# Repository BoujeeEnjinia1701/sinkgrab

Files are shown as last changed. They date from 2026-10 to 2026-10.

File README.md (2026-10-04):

# SinkGrab

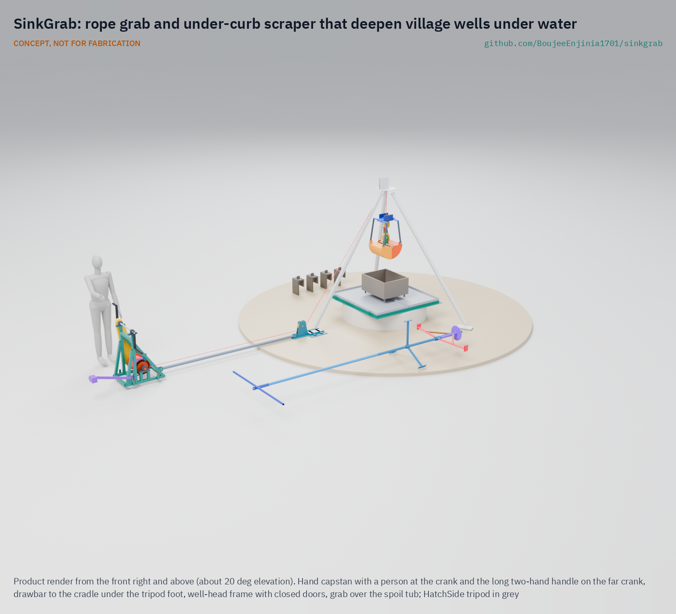
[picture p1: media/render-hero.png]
SinkGrab: rope grab and under-curb scraper that deepen village wells under water


     

**Area:** Food and water security · **TRL:** 3 of 9 (proof of concept on paper; constructable design) · **Value-engineering target:** USD 4,000; estimated parts cost USD 2,566 · **Difficulty:** 3 of 5

Deepens village wells under water with a rope grab and under-curb scraper, without divers or pumps.

> CONCEPT, NOT FOR FABRICATION. SinkGrab is a TRL 3 design on paper: it has not been built or tested.

## Concept rationale

A hand-dug well only gives water all year if its intake sits well below the lowest seasonal water level. Guidance for caisson wells is to keep excavating and sinking rings typically 2 to 3 m below the water table ([Abbott, Hand Dug Wells manual](https://sswm.info/sites/default/files/reference_attachments/ABBOT%204000%20Hand%20Dug%20Well%20Manual.pdf)). Without de-watering the practical limit is about 1 m ([Akvopedia](https://akvopedia.org/wiki/Traditional_hand-dug_wells)). The usual answers are a motor pump to bail the well, or a person working under water. SinkGrab removes both: the digging and the undercutting are done by tools on ropes, worked from the surface.

SinkGrab is two tools and a routine. A rope-closed grab bites soil from the bottom of the flooded well inside the caisson rings and lifts it out. An under-curb scraper reaches under the cutting edge of the bottom ring so the lining sinks evenly as the soil is removed. Both hang from the HatchSide tripod and are worked with a hand capstan, so the crew stays at the top. Everything is built from steel section, rope and hand tools, and is published under open licences so village fabricators can copy and repair it.

## Burning platform

About 296 million people still drink from unprotected wells or springs ([Our World in Data, from WHO/UNICEF JMP 2024](https://ourworldindata.org/what-no-safe-water-means)). Many more rely on protected hand-dug wells that fail in the dry season: 'Hand-dug wells have a tendency to have very little water or even dry up in the dry season', largely because the intake is not deep enough below the seasonal water table, which can move several metres between seasons ([Akvopedia](https://akvopedia.org/wiki/Traditional_hand-dug_wells)). In Ethiopia's 2015/16 drought, hand-dug wells dried up while monitored boreholes kept the same flow all year, and people without boreholes queued for up to 10 hours for water ([BGS](https://www.bgs.ac.uk/news/study-shows-boreholes-are-key-to-drought-resilience-in-ethiopia/)).

Going deeper under water is dangerous. Oxfam's guidance says a diesel or petrol pump or its engine must never be lowered into a well, because carbon monoxide collects there ([Oxfam WASH](https://www.oxfamwash.org/repairing-cleaning-and-disinfecting-hand-dug-wells/)). In August 2023 three men died in Mutare, Zimbabwe, while draining a well about 19 m deep with a petrol pump ([ZimLive, 2023](https://www.zimlive.com/3-killed-in-carbon-monoxide-poisoning-after-turning-on-generator-in-a-well/)). In August 2026 four men died of suspected toxic gas while repairing a motor inside a well in Gaya Ji, Bihar ([The Tribune, 2026](https://www.tribuneindia.com/news/india/4-die-of-asphyxiation-after-inhaling-toxic-gas-inside-well-in-bihars-gaya-ji/)). Every hour a person spends at the bottom of a well is exposure; tools that dig from the surface cut that exposure.

## Where it could be used

### By industry

| Industry | Use |
| --- | --- |
| Rural water supply and WASH programmes | Deepening existing hand-dug wells so they last through the dry season |
| Well-digging contractors and village fabricators | A safer, pump-free way to finish the wet part of a new caisson well |
| Smallholder irrigation | Deepening dug wells used for garden and livestock water |
| Drought and humanitarian response | Rehabilitating dry community wells quickly with a kit that travels on a pickup |
| Small civil works | Sinking small precast caissons for pump sumps and soakaways |
| Engineering education | A documented case study in caisson sinking, rope mechanics and field safety |

### By country or region

| Country or region | Why it matters there |
| --- | --- |
| India (Kerala) | About 65% of rural and 59% of urban households depend on wells, and 48% of 45 lakh wells surveyed in 2003 dried up in summer ([SOPPECOM, citing Census 2011 and the Kerala Water Authority](https://www.soppecom.org/pdf/Groundwater-Resource-and-Governance-in-Kerala.pdf)). |
| India (Thiruvananthapuram) | Well diggers report that in summer they must dig an extra 10 to 15 feet (3 to 4.5 m) down, and one crew dug more than 70 wells in three months ([Deccan Chronicle, 2017](https://www.deccanchronicle.com/nation/in-other-news/040517/thiruvananthapuram-well-diggers-strike-gold-in-summer.html)). |
| Ethiopia | In the 2015/16 drought hand-dug wells dried up and many became grossly contaminated, while boreholes held their flow ([BGS](https://www.bgs.ac.uk/news/study-shows-boreholes-are-key-to-drought-resilience-in-ethiopia/)). |
| Zimbabwe | Three men died of carbon monoxide in 2023 while draining a 19 m well with a petrol pump, the risk SinkGrab is designed to remove ([ZimLive, 2023](https://www.zimlive.com/3-killed-in-carbon-monoxide-poisoning-after-turning-on-generator-in-a-well/)). |
| Global | About 296 million people use unprotected wells or springs ([Our World in Data, 2024 JMP data](https://ourworldindata.org/what-no-safe-water-means)); upgrading and deepening dug wells is one of the cheapest paths to year-round water for them. |

## What sparked the idea

In August 2023 three men in Mutare, Zimbabwe, were draining a well about 19 m deep so they could work at the bottom. The petrol pump they used filled the shaft with exhaust and all three died ([ZimLive, 2023](https://www.zimlive.com/3-killed-in-carbon-monoxide-poisoning-after-turning-on-generator-in-a-well/)). Oxfam's field guidance forbids exactly this ([Oxfam WASH](https://www.oxfamwash.org/repairing-cleaning-and-disinfecting-hand-dug-wells/)), yet the job still has to be done, because a well that is not deep enough goes dry. SinkGrab starts from that gap: if the water cannot safely be taken out, the soil has to be.

## Problem

Hand-dug wells go dry in the dry season because crews cannot dig far enough below the water table without pumps, and pumps and divers in wells kill people. Well diggers need a way to keep digging under water and sink the lining from the surface.

Full problem statement: [docs/01-problem.md](docs/01-problem.md)

## Concept

A rope grab and under-curb scraper worked from the HatchSide tripod and a hand capstan; well diggers lower them into a flooded hand-dug well to dig soil out under water and undercut the curb ring so the lining sinks, without divers or pumps. One 8 mm line does everything: the grab goes down closed, its head's weight opens it on the bottom, and two people at the cranks, three during the hoist, close it through a 3:1 tackle on a bite of about 21 L and lift it. A shear link and a crank shear pin keep the line inside the tripod's 150 kg rating. The scraper's arms open under the cutting edge when the pole's weight rests on its foot, and two people turn it with a T-bar through the closed well-head doors.

Full design precis: [docs/02-concept.md](docs/02-concept.md) · Requirements: [docs/03-requirements.md](docs/03-requirements.md) · Calculations: [docs/04-calcs/01-sizing.md](docs/04-calcs/01-sizing.md) · Prototype build plan: [docs/05-build-plan.md](docs/05-build-plan.md) · Design decisions: [docs/06-design-decisions.md](docs/06-design-decisions.md)

## Key components

- Hand capstan: winding drum, 4:1 chain with a shear pin hub, pawl, weighted band brake, removable cranks
- Foot cradle with lead sheave under the HatchSide leg A foot, and a drawbar back to the capstan
- Two-shell clamshell grab on one closing line, with a shear link at its tackle
- Under-curb scraper head on 2 m pole sections, turned with a T-bar
- Well-head frame with folding doors, pole hole and tilt datum; spoil tubs
- Ballast saddles (8) and a dip tape and plumb line for tilt
- Four-gas detector and barrier kit

## Building the prototype

The capstan, cradle, drawbar, grab, scraper, well-head frame and saddles are welded from stock steel tube, plate and bar, with the shell skins rolled and a few plates profile-cut; the bearings, chain drive, sheaves, ropes and rigging are bought. The build plan takes a capable maker through every component in build order with a making sketch, joint close-ups and a picture for each of its 20 assembly steps, and lists the safety stops before anything is lifted over a well. It is a plan, not yet built.

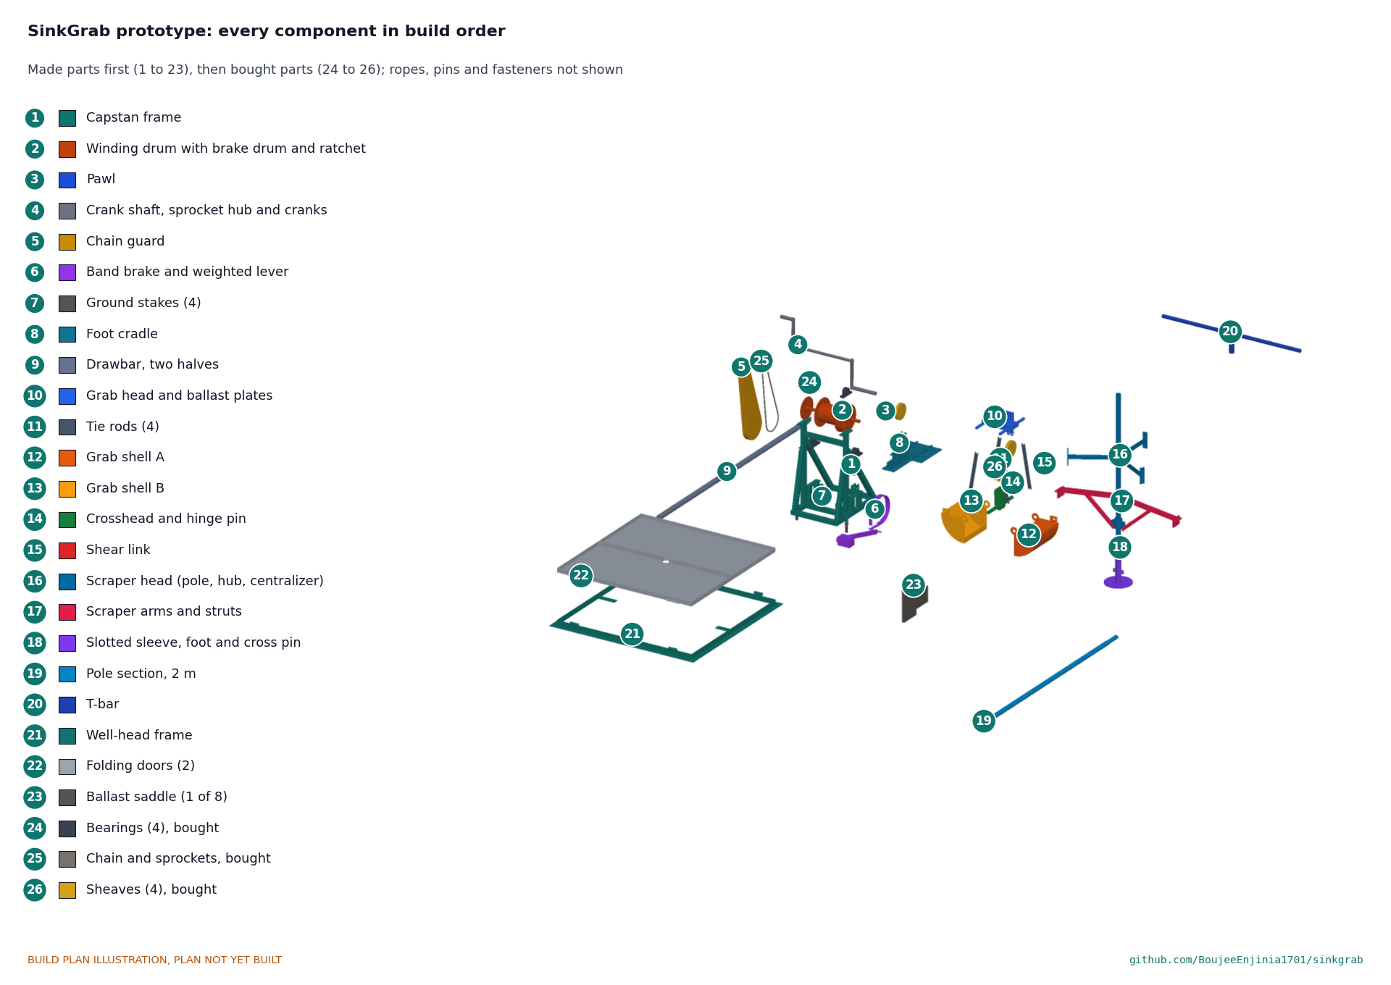
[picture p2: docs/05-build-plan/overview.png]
SinkGrab prototype: every component in build order


## Safety

> Published as an open engineering reference, not certified lifting or well-construction equipment.
>
> This is lifting equipment over an open shaft: the tripod, capstan, hooks and ropes must be proof-loaded (CalRig) and inspected before use, and nobody stands under a suspended load.
>
> No one enters the well while the grab or scraper is in use. Any entry needs a gas test, a harness on a separate line and a person at the top at all times.
>
> Never lower or run a petrol or diesel engine in or beside the well mouth; exhaust collects in the shaft.
>
> Undercutting can make rings drop suddenly or tilt; scrape evenly, keep a controlled sump and stop if tilt exceeds the limit.
>
> Keep a barrier and cover around the well head to prevent falls.
>
> The line is limited by a calibrated shear link and a crank shear pin so the HatchSide tripod is never loaded past its rating; replace them only with the specified pins, never a bolt. The well-head doors are closed whenever the grab is up, and the cranks come off before lowering on the brake. Stop and correct when tilt passes 1 in 160; stop undercutting at 1 in 80. See the safety stops in the [build plan](docs/05-build-plan.md).
>
> This design is published as an open engineering reference. It is not certified equipment.

## Repository layout

| Folder | Contents |
| --- | --- |
| `docs/` | Problem, concept, requirements, calculations, build plan and design decisions |
| `cad/src/` | build123d Python source, the source of truth for all geometry |
| `cad/step/`, `cad/stl/` | Exported models for FreeCAD, other CAD tools and printing |
| `cad/drawings/` | 2D sketches and dimensioned drawings |
| `bom/` | Bill of materials |
| `electronics/` | KiCad schematics and PCB layouts |
| `firmware/` | Microcontroller code |
| `media/` | Renders, perspectives and photos |
| `build-log/` | Dated prototyping notes |

## Documentation

Controlled documents follow the portfolio [documentation standard](.kit/STANDARDS.md). Each carries a document ID (SKG-PRC-001 for the precis), a version and a revision history. Branded PDFs are built with `python .kit/render.py` and attached to GitHub Releases when a document is tagged, for example `SKG-PRC-001/v1.0`.

## Credits

Designed by Amish Chadha at Design Molecule Labs. See [CONTRIBUTORS.md](CONTRIBUTORS.md) for roles. To cite this design, use [CITATION.cff](CITATION.cff) (GitHub shows it as "Cite this repository").

AI assistance (Claude) was used to accelerate prototype documentation and first-pass research. Design direction and all decisions are Amish Chadha's, recorded in this repository's decision records (`docs/decisions/`).

## Licenses

- **Hardware** (CAD, drawings, BOM, electronics): [CERN-OHL-S v2](LICENSE)
- **Software** (firmware, scripts, notebooks): [MIT](LICENSE-SOFTWARE)

A project of the [Design Molecule](https://designmolecule.com) lab.

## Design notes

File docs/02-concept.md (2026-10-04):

---
doc_id: SKG-PRC-001
title: SinkGrab design precis
project: SinkGrab
doc_type: Precis
version: "0.5"
status: Draft
date: '2026-10-04'
author: Amish Chadha
license: CERN-OHL-S-2.0
revisions:
- version: "0.1"
  date: '2026-09-30'
  author: Amish Chadha
  change: Initial scaffold
- version: "0.2"
  date: '2026-10-03'
  author: Amish Chadha
  change: TRL 2 precis; single closing line with a gravity-opening grab, overload limits, centred scraper pole, doors and saddles (SKG-DDR-001)
- version: "0.3"
  date: '2026-10-03'
  author: Amish Chadha
  change: TRL 3 numbers from SKG-CAL-001 on the constructable design (SKG-DDR-002); concept media from the model
- version: "0.4"
  date: '2026-10-03'
  author: Amish Chadha
  change: "Amish's decisions 27A, 28B and 29B of 2026-10-03 (SKG-DDR-003): third person at the cranks during the hoist, 3:1 closing tackle, toe blades 40 mm past the ring; numbers from SKG-CAL-001 v0.2"
- version: "0.5"
  date: '2026-10-04'
  author: Amish Chadha
  change: "Amish's round-3 decision 5A of 2026-10-04 (SKG-DDR-004): 340 mm slotted sleeve on a 12 mm cross pin in place of the stop collar, so the scraper's arms fold to pass the ring; cost from SKG-CAL-001 v0.3"
---

# SinkGrab design precis

Deepens village wells under water with a rope grab and under-curb scraper, without divers or pumps.

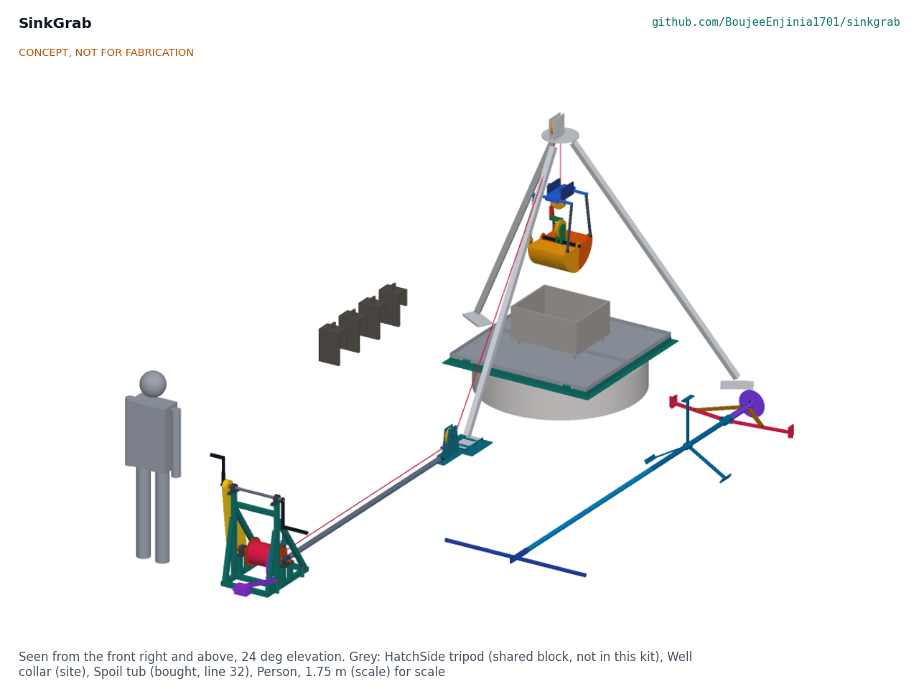
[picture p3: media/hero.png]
Figure 1. SinkGrab at the well head


*Figure 1. SinkGrab at the well head: hand capstan, drawbar and lead cradle on the left, well-head frame with its doors closed, the grab at the dump position over a spoil tub, the scraper and ballast saddles on the ground. The HatchSide tripod is shown in grey. Concept, not for fabrication.*

## Summary

SinkGrab lets a village crew dig the last 3 m of a caisson well under water from the surface. A clamshell grab on one rope digs sand out of the flooded rings, an under-curb scraper on a pole cuts the soil from under the bottom ring so the lining sinks, and a hand capstan worked by two people, three during the hoist, does the lifting through the HatchSide tripod. On paper it lifts 21 L a bite with 54 N on each crank handle and never loads the tripod past its 150 kg rating; the cycle at 10 m is about 3.2 min, 6 % over the 3 min target, which the timed trial decides. The parts cost about USD 2,566 against a value-engineering target of USD 4,000.

## How it works

The crew stands the HatchSide tripod over the well and replaces its winch with SinkGrab's line: an 8 mm rope runs from the hand capstan on the ground, through a lead sheave in a cradle under the tripod's leg A foot, up beside the leg, over the head sheave and straight down the well. A drawbar joins the capstan to the cradle, so the rope pull is carried inside the kit and the tripod sees the same loads as with its own winch.

The grab is lowered closed on the capstan's band brake. On the bottom the crew slacks the line by about 0.3 m: the grab's head settles under its own weight and pushes the two shells open into the sand. Cranking then pulls the crosshead up toward the head through a 3:1 tackle inside the grab (under the crosshead sheave, over an upper sheave in the head, down to the shear link on the crosshead), which closes the shells on a bite and lifts it. A third person joins the cranks for the hoist on a long two-hand handle. At the top the crew closes the well-head doors under the grab, lowers it into a spoil tub standing on them and slacks the line again: the shells open and the sand falls into the tub. Cranking closes the empty grab and lifts it off; the doors open and the cycle repeats.

When the centre has been dug about 330 mm below the cutting edge, the scraper goes down on 2 m pole sections. Its foot lands in the sump, the pole's weight slides it down through the foot sleeve, and two struts push two arms out until the blades on their toes reach 40 mm beyond the ring's outer face, under the cutting edge, so the ring slides down through loosened soil. Two people turn the pole with a T-bar through the hole in the closed doors, and the toes cut a ring of soil from under the wall, which the grab then removes. Lifting the pole lets the sleeve slide 300 mm down it on a cross pin running in two slots, which folds the arms to pass the ring.

Every cycle the crew reads the dip tape at four datum holes on the well-head frame. If one side is ahead, they scrape only on the high side and hang ballast saddles on the high side of the top ring.

## Main components

*Table 1. Components (numbers are bill of materials lines).*

| # | Component | Role |
| --- | --- | --- |
| 1 to 7 | Hand capstan: frame, winding drum with brake drum and ratchet wheel, pawl, crank shaft with shear pin hub, removable cranks, chain guard, weighted band brake, stakes | Two-person hoist; holds the load at any depth, limits the line pull |
| 8, 9 | Foot cradle with lead sheave, and drawbar | Turns the line up leg A; carries the pull back to the capstan |
| 10 to 14 | Clamshell grab: head with ballast plates and upper sheave, tie rods, two shells, crosshead with hinge pin, sheave and dead-end arm, shear link | Digs and lifts 21 L a bite under water on one line |
| 15 to 17 | Under-curb scraper head, 2 m pole sections, T-bar | Cuts the soil from under the ring's cutting edge |
| 18, 19 | Well-head frame with datum brackets, folding doors | Covers the shaft, carries the spoil tub, guides the pole, holds the tilt datum |
| 20 | Ballast saddles (8) | Add weight on the high side of the top ring |
| 21 to 34 | Bought: bearings, chain drive, shear pins, sheaves, ropes, swivel and shackles, dip tape and plumb line, gas detector, spoil tubs, barrier kit, fasteners | |

## Numbers from the TRL 3 calculations

*Table 2. First-order numbers (SKG-CAL-001).*

| Quantity | Value | Assumption or basis |
| --- | --- | --- |
| Bite | 21.2 L (28.3 L closed) | 75 % fill in loose saturated sand |
| Closing force | About 685 N at the lips, 1.06 of the line pull | 3:1 tackle |
| Grab mass | 51.0 kg; 96 kg full in air | Sand 2.0 kg/L, 3 L of water |
| Working line pull | 1,041 N | 1.1 for hand hoisting |
| Crank force at rated load | 54 N each, two people | 4:1 chain, 250 mm cranks, outer layer |
| Hoist speed | 5.8 m/min with two people | 50 W per person |
| Cycle at 10 m | 3.17 min with three at the cranks during the hoist (3.8 min with two) | Lowering 0.5 m/s on the brake |
| Crank shear pin | Line limited to 2,107 N | 3 mm S235, ±20 % |
| Shear link | Releases at 1,202 to 1,469 N | Pin break-tested, ±10 % |
| Tripod | Inside its 150 kg rating and 225 kg proof | HatchSide HTS-CAL-001 |
| Scraper | 142 N each on the T-bar; toe blades 40 mm past the ring; fold to 389 mm radius | 150 N per toe in loose sand |
| Sinking | Continues while skin friction is below 1.66 kPa | 8-ring string, 8 saddles |
| Heaviest piece | 22.9 kg (capstan frame), the scraper arms carried unpinned | Model masses |
| Parts cost | USD 2,566 | Value-engineering target USD 4,000 |

## Key design choices

All decided under Amish's pre-approvals of 2026-10-03 (SKG-DDR-001 and SKG-DDR-002); the third person at the cranks, the 3:1 tackle and the toe blades by Amish's decisions of 2026-10-03 (SKG-DDR-003).

- **One line does everything.** A two-line grab needs a second winch and two people keeping two ropes in step. SinkGrab's grab is lowered closed and opened by its own head weight, so one capstan and one rope dig, lift and dump.
- **The tripod never sees more than its rating.** A calibrated shear link at the grab's tackle releases between 1.20 and 1.47 kN and opens the grab if it snags; a 3 mm shear pin in the crank hub caps the line at 2.1 kN, under the tripod's proof load, whatever two people do at the cranks.
- **The rope pull stays inside the kit.** The drawbar between the capstan and the cradle under the leg A foot means nothing is anchored to the ground but the tripod's own feet.
- **The brake is on unless someone holds it off.** A weighted lever applies the band brake when it is let go; the cranks come off before any lowering.
- **The scraper is centred and opened by weight.** A pole with a centralizer reaches any depth to 25 m, and its own weight opens the arms only when the foot is on the sump floor.
- **Doors over the shaft.** The well is covered whenever the grab is up; the doors also carry the spoil tub, guide the pole and hold the tilt datum.

## Patent design-arounds

From the preliminary patent, trademark and prior-art screen (not legal advice):

- Rope grab and scraper only; no sand dredger or suction dredging, to stay clear of CN101787703B (China 22MCC Group, active to about 2030).
- A targeted search of Chinese open-caisson excavator patents for under-curb scraper claims is run before public release (decided, SKG-DDR-001, item 14).
- US1750728A (well-tool grab) is expired and a different tool; no constraint.

## Relationship to other lab projects

- **HatchSide** provides the tripod. SinkGrab removes the HatchSide winch, fits a 150 mm sheave grooved for its 8 mm line in the HatchSide head, and clamps its cradle under the leg A foot. Nothing in HatchSide is changed.
- **SiltHaul and SaltDrag** share the hand capstan block: the same frame layout, 4:1 chain, shear pin hub and pawl, here with a single drum and a band brake.
- **CalRig** is the first candidate rig for the proof loads.

## Safety

> **Safety:** SinkGrab is lifting equipment worked over an open well shaft, with a hand-cranked chain drive and loads hanging over the well. The hazards are falls into the shaft, loads or tools falling into the well or onto people, rope or pin failure, fingers and clothing caught in the chain, drum or brake, bad air in the shaft, and rings dropping or tilting suddenly as they are undercut.
>
> - Nobody enters the well while SinkGrab is in use. Any entry for another reason needs a gas test, a harness on a separate line from separate rescue equipment, and a person at the top throughout. SinkGrab's line is never used to lift or lower a person.
> - Test the shaft air with the four-gas detector before work starts each day and after any break. Never run a petrol or diesel engine in or near the well mouth.
> - The doors are closed whenever the grab is above them and at every stop. A barrier stands 2 m outside the tripod feet.
> - Every lifting part is proof-loaded before first use (SKG-BLD-001, section 6). Nobody stands under the grab or beside the line while it is loaded.
> - The shear pins are always the specified mild steel pins, never a bolt or a nail.
> - The cranks come off before lowering on the brake; the chain guard stays on.
> - Stop and correct when tilt passes 1 in 160; stop all undercutting at 1 in 80 until it is corrected.
>
> This design is published as an open engineering reference. It is not certified lifting or well-construction equipment.

## Open questions

The open questions of SKG-PRB-001 v0.1 were answered on paper at TRL 2 (SKG-DDR-001). What only trials can answer is listed in SKG-PRB-001, "Questions for the first trials". Three requirements await Amish's decision in the design decisions register (SKG-DEC-001): R1, R3 and R4.

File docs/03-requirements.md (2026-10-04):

---
doc_id: SKG-REQ-001
title: SinkGrab requirements
project: SinkGrab
doc_type: Requirements
version: "0.5"
status: Draft
date: '2026-10-04'
author: Amish Chadha
license: CERN-OHL-S-2.0
revisions:
- version: "0.1"
  date: '2026-09-30'
  author: Amish Chadha
  change: Initial scaffold
- version: "0.2"
  date: '2026-10-03'
  author: Amish Chadha
  change: TRL 2 requirements with concept status (SKG-DDR-001); R11 restated against the value-engineering target
- version: "0.3"
  date: '2026-10-03'
  author: Amish Chadha
  change: TRL 3 status from SKG-CAL-001 on the constructable design (SKG-DDR-002); R1 and R3 at risk and R4 not met, each posed to Amish as a decision in SKG-DEC-001
- version: "0.4"
  date: '2026-10-03'
  author: Amish Chadha
  change: "Amish's decisions 27A, 28B and 29B of 2026-10-03 (\"i agree with all the 46 recommendations you provided. please proceed.\"), SKG-DDR-003: R4 restated for three people at the cranks during the hoist; status of R1, R3, R4, R5, R7, R9 and R11 from SKG-CAL-001 v0.2"
- version: "0.5"
  date: '2026-10-04'
  author: Amish Chadha
  change: "Amish's round-3 decision 5A of 2026-10-04 (\"For round 3, I agree with all your proposed recommendations\"), SKG-DDR-004: slotted sleeve and cross pin give the scraper's arms the 300 mm of sleeve travel they need to fold; status of R2, R9 and R11 from SKG-CAL-001 v0.3; no requirement restated"
---

# SinkGrab requirements

Eight of the eleven requirements are met on paper or by design, one can only be shown in a field trial, one is at risk and one is not met on paper by a small margin (SKG-CAL-001 v0.2, section M). Amish decided the three open requirements on 2026-10-03 ("i agree with all the 46 recommendations you provided. please proceed."; SKG-DDR-003): a third person at the cranks during the hoist (R4, restated below), a 3:1 closing tackle (R3) and toe blades that cut 40 mm past the ring's outer face (R1). The cycle time (R4) is now about 3.2 min at 10 m, 6 % over the target; the timed trial decides it. The depth gained (R1) still depends on how much the soil grips the sinking rings, which only the first trial can measure. On 2026-10-04 Amish decided the scraper sleeve's travel ("For round 3, I agree with all your proposed recommendations"; SKG-DDR-004): a 340 mm slotted sleeve on a 12 mm cross pin, so the arms fold to pass the ring and R2 is met by design as stated. "Met on paper" means shown by calculation, not by test.

> **Safety:** SinkGrab is lifting equipment worked over an open well shaft. R7 (proof load) and R8 (nobody in the well) are its safety requirements, and the overload limits behind R7 (a crank shear pin and a shear link, SKG-CAL-001, section C) are checked on paper only. Every lifting part must be proof-loaded before use (SKG-BLD-001, section 6).

Table 1. Requirements and status at TRL 3

| ID | Requirement | Target | Verification (TRL 3 or later) | Status (SKG-CAL-001) |
| --- | --- | --- | --- | --- |
| R1 | Deepen a flooded caisson well below the water table without de-watering | At least 3 m of standing water depth reached (target) | Field trial in a partner well, measured with the dip tape before and after | **At risk:** the 8-ring string sinks only while skin friction stays below about 1.7 kPa; estimated 1 to 3 kPa; the toes now cut 40 mm past the ring's outer face to keep it low (decision 29B); friction measured in the first trial |
| R2 | Fit common caisson ring sizes | Works inside rings of 0.8 to 1.3 m internal diameter | Fit check in rings of three sizes | Met by design: grab 468 mm across; scraper folds to 389 mm radius on 300 mm of sleeve travel (slotted sleeve and cross pin, SKG-DDR-004); toes, skids and a longer arm pair cover the range |
| R3 | Grab load per cycle | At least 20 L of saturated sand per bite (target) | Test pit trials with a measured tipping bin | Met on paper at the assumed fill: 21.2 L at 75 % fill, closed by a 3:1 tackle with 50 % more lip force (decision 28B); 14.1 L at 50 %; fill confirmed in the test-pit trial |
| R4 | Cycle time | 3 min or less per grab cycle at 10 m depth with three people at the cranks during the hoist and two otherwise (target; restated 2026-10-03, decision 27A) | Timed trial over 20 cycles | **Not met on paper by about 0.2 min:** 3.17 min with three at the hoist (3.8 min with two); the timed trial decides |
| R5 | Operator effort | Crank force 150 N or less per operator at rated grab load (target) | Spring balance on the crank handle during lifts | Met on paper: 54 N each with two people (108 N for one) |
| R6 | Keep the lining vertical while sinking | Tilt no worse than 1 in 80, the allowance used for sunk well foundations ([Construction Civil](https://www.constructioncivil.com/well-sinking-tilt-shift-in-well-foundation/)) | Four-point dip tape readings every cycle during trials | Not verifiable at TRL 3: readings resolve about 1 in 250; correction by scraping the high side and saddles |
| R7 | Proof load of lifting parts | Tripod, capstan, hooks and rigging proof-loaded to 2 times working load (target) | CalRig proof-load test with record | Met on paper: proof 193 kg, inside the HatchSide proof of 225 kg; line factor 10.4; shear link margin 1.15 |
| R8 | No person in the well during digging | 100% of digging and undercutting done from the surface | Trial log and method statement review | Met by design: every task from the surface; doors cover the shaft |
| R9 | Portability | Heaviest single piece 25 kg or less; kit fits in a small pickup (target) | Weigh each piece; load trial | Met on paper: heaviest piece 22.9 kg (capstan frame) with the scraper arms carried unpinned (scraper head 26.1 kg with them on, 20.1 kg without); kit about 457 kg, longest piece 2.0 m |
| R10 | Local build | Built with a stick welder, drill and hand tools from common steel section | Build by a partner workshop from the published drawings | Met by design; the shell skins need plate rolls, which most fabricators have |
| R11 | Prototype cost | At or under the USD 4,000 value-engineering target (a hypothetical control target) | Bill of materials and receipts | Met on paper, within the target: USD 2,566 (USD 1,434 under) |

## Requirements at risk or not met

Amish decided each of these on 2026-10-03 ("i agree with all the 46 recommendations you provided. please proceed."); the records are SKG-DDR-003 and SKG-DEC-001.

- **R4 (not met on paper by about 0.2 min).** Restated by decision 27A: the target is 3 min a cycle at 10 m with three people at the cranks during the hoist. Hand power still sets the hoist: 76 s of the 3.17 min cycle. The timed trial over 20 cycles decides.
- **R3 (met on paper at the assumed fill).** Decision 28B: a 3:1 tackle closes the lips 50 % harder (about 685 N). The fill is confirmed in the test-pit trial.
- **R1 (at risk).** Decision 29B: toe blades cut 40 mm past the ring's outer face to loosen the soil against it. Sinking still stops if skin friction exceeds about 1.7 kPa; the first trial measures it.

## Assumptions

- Crews already use precast caisson rings of a smaller diameter below the water table; the design case is a 1.0 m ring with a 75 mm wall inside a 1.3 m lining.
- Soils at the target sites can be taken by a clamshell grab; boulders and hard rock need a separate method.
- The HatchSide tripod keeps its 150 kg rating for material handling; SinkGrab's overload limits keep the line inside it.
- Three people are available to work the capstan for a full day (two between hoists, three during the hoist); a crew of four or five works the site.

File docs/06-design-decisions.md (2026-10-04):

---
doc_id: SKG-DEC-001
title: SinkGrab design decisions register
project: SinkGrab
doc_type: Design decisions register
version: "0.3"
status: Draft
date: '2026-10-04'
author: Amish Chadha
license: CERN-OHL-S-2.0
revisions:
- version: "0.1"
  date: '2026-10-03'
  author: Amish Chadha
  change: Register opened; design decisions made under Amish's pre-approvals of 2026-10-03; three requirement decisions (R4, R3, R1) proposed, awaiting Amish
- version: "0.2"
  date: '2026-10-03'
  author: Amish Chadha
  change: "Amish's round-2 decisions 27A, 28B and 29B of 2026-10-03 moved to Decisions made (SKG-DDR-003); one new decision posed: the scraper sleeve's travel"
- version: "0.3"
  date: '2026-10-04'
  author: Amish Chadha
  change: "Amish's round-3 decision 5A of 2026-10-04 (scraper sleeve travel) moved to Decisions made (SKG-DDR-004); no open decisions"
---

# SinkGrab design decisions register

Every design decision still to be made, and every decision made, in one place. Each decision is argued in full in its decision record under `docs/decisions/` or in `docs/REVIEW.md`; this register is the index Amish works from. The build plan (`docs/05-build-plan.md`) describes the design as it stands and does not list decisions.

> **Safety:** Several decisions below set SinkGrab's safety case (overload limits, lowering on a brake that is on when let go, the doors over the shaft, no entry). Each took the conservative option; the evidence that would relax it is in SKG-DDR-001, Table 1. None of the requirement decisions of 2026-10-03 and 2026-10-04 changes the safety case.

## Open decisions

None. Every decision posed so far has been made by Amish: R4, R3 and R1 on 2026-10-03 and the scraper sleeve's travel (R2) on 2026-10-04 (below). Requirements that are not met or at risk on paper are posed to Amish as a state, options and a recommendation (Amish, 2026-10-03: "A simple statement doesn't add value - ensure you are identifying a state and posing it as a clear recommendation for me to decide on"); what remains of R4 and R1 is settled by the timed trial and the first well trial, as already decided.

## To confirm when parts are bought

| # | What to confirm | Why it matters | Source |
| --- | --- | --- | --- |
| 1 | Release load of the link pins from the coil bought, by breaking three pins | The link must release between 1.20 and 1.47 kN; the pin diameter (about 1.9 mm) is chosen from these breaks | SKG-CAL-001, C |
| 2 | Release of the 3 mm crank shear pins from the bar bought | Sized on 240 MPa shear; a stronger bar lets the line pass the tripod's proof load | SKG-CAL-001, C |
| 3 | Breaking strength and splice of the 8 mm rope bought | Factors assume 12 kN and 90 % at the splice | SKG-CAL-001, E |
| 4 | Sheave groove, bore and width fit the HatchSide cheeks and 20 mm axle, and the grab head's cheeks 30 mm apart | The head sheave is swapped while SinkGrab works; the upper sheave of the 3:1 tackle uses the same sheave | SKG-DDR-002, item 2; SKG-DDR-003 |
| 5 | HatchSide foot plate size and thickness on the tripod as built | The cradle rim and clamp bars are sized on 140 x 280 mm | SKG-DWG-107 |
| 6 | Brake lining friction on the steel drum | Holding torque assumes 0.35 | SKG-CAL-001, F |
| 7 | Bearing centre heights and bolt pitches | Pads and top plates are drilled to UCP206 and UCP205 catalogue sizes | SKG-DWG-101 |
| 8 | Ring size and wall thickness at the trial well | Toe position, skid holes and saddle slot are set for a 1.0 m ring with a 75 mm wall | SKG-DWG-112, 113, 117 |
| 9 | The sleeve slides the full 300 mm of its slots on the cross pin, and the arms fold to inside an 800 mm circle | The head must pass a 0.8 m ring when lifted | SKG-DDR-004; SKG-DWG-113 |

## Value engineering

Value-engineering target: USD 4,000 (a hypothetical control target, not a limit). Estimated cost of the constructable design: USD 2,566 (USD 1,434 under the target). Main cost drivers and savings worth trying:

- The four-gas detector (USD 550) is the largest line; a crew or partner that already owns a pumped detector saves it.
- The eight ballast saddles (USD 240) and their lines (USD 100): saddles cast in concrete inside a steel strap would cost less, at more bulk.
- The two grab shells (USD 120) need plate rolls; a fabricator with rolls is the cheapest route, a cut-and-fold faceted skin the fallback.
- The pole sections (USD 108 for six) scale with well depth.

## Decisions made

| Date | Decision | Decided by | Record |
| --- | --- | --- | --- |
| 2026-10-03 | Two-shell clamshell grab worked on one closing line, opened by the head's weight | Amish: "I pre-approve the batch runs along with any recommendations you come up with." and "Proceed with the remaining 15 scaffolds" | SKG-DDR-001, items 1, 2 |
| 2026-10-03 | Shear link (1.20 to 1.47 kN) and 3 mm crank shear pin keep the line inside the HatchSide rating and proof load | Amish, as above | SKG-DDR-001, item 3 |
| 2026-10-03 | SinkGrab hand capstan (single drum, 4:1 chain, pawl, band brake) in place of the HatchSide winch | Amish, as above | SKG-DDR-001, item 4 |
| 2026-10-03 | Drawbar to a cradle under the leg A foot; no ground anchors | Amish, as above | SKG-DDR-001, item 5 |
| 2026-10-03 | Lowering on a weighted band brake with the cranks removed | Amish, as above | SKG-DDR-001, item 6 |
| 2026-10-03 | Centred scraper pole with centralizer and weight-opened arms | Amish, as above | SKG-DDR-001, item 7 |
| 2026-10-03 | No de-watering; sump at most 330 mm below the cutting edge | Amish, as above | SKG-DDR-001, item 8 |
| 2026-10-03 | Tilt read every cycle; correct from 1 in 160; stop undercutting at 1 in 80 | Amish, as above | SKG-DDR-001, item 9 |
| 2026-10-03 | Ballast saddles on their own lines in place of a ballast frame | Amish, as above | SKG-DDR-001, item 10 |
| 2026-10-03 | Well-head frame with folding doors and spoil tubs in place of a chute and tipping hook | Amish, as above | SKG-DDR-001, item 11 |
| 2026-10-03 | First co-design candidate to approach: Kerala Ground Water Department (not agreed); second, a rural water NGO in the Ethiopian highlands | Amish, as above | SKG-DDR-001, item 12 |
| 2026-10-03 | HatchSide tripod used with a swapped 8 mm head sheave; SinkGrab capstan recorded as the single-drum variant of the common capstan block; CalRig as first candidate proof-load rig | Amish, as above | SKG-DDR-001, item 13 |
| 2026-10-03 | Targeted patent search for under-curb scraper claims before public release | Amish, as above | SKG-DDR-001, item 14 |
| 2026-10-03 | `budget_usd` kept at 4,000 as a value-engineering target | Amish: "I also accept any cost overruns or variations from the assumed scope cost." | SKG-DDR-001, item 15 |
| 2026-10-03 | Design for construction: the fifteen changes of SKG-DDR-002 | Amish, as for item 1 | SKG-DDR-002 |
| 2026-10-03 | Scraper working limit 25 m (12 pole sections) | Amish, as for item 1 | SKG-CAL-001, H |
| 2026-10-03 | Appearance model additions for renders: wound rope, context collar, ground, tub, ring pieces and mannequin | Amish, as for item 1 | docs/REVIEW.md, TRL 3 |
| 2026-10-03 | R4 (item 27A): a third person on the cranks during the hoist, on a 240 mm two-hand handle on the +X crank; R4 restated for three people at the hoist; cycle 3.17 min, about 0.2 min over, the timed trial decides | Amish: "i agree with all the 46 recommendations you provided. please proceed." | SKG-DDR-003, item 1 |
| 2026-10-03 | R3 (item 28B): a 3:1 closing tackle, with an upper sheave under the head and the dead end and shear link on the crosshead; lip force about 685 N (+50 %); USD 35, 3.1 kg | Amish, as above | SKG-DDR-003, item 2 |
| 2026-10-03 | R1 (item 29B): toe blades cutting 40 mm past the ring's outer face; USD 10, 0.4 kg; friction measured in the first trial | Amish, as above | SKG-DDR-003, item 3 |
| 2026-10-04 | Scraper sleeve travel (R2, item 5A): a 340 mm sleeve with a 13 x 312 mm slot each side and a 12 mm cross pin through the pole running in the slots, in place of the stop collar; sleeve travel 300 mm, arms fold to 389 mm radius; USD 5, 0.9 kg (head with arms unpinned 20.1 kg) | Amish: "For round 3, I agree with all your proposed recommendations" | SKG-DDR-004 |

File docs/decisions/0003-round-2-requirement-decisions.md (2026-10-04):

---
doc_id: SKG-DDR-003
title: SinkGrab requirement decisions of 2026-10-03 (R4, R3, R1)
project: SinkGrab
doc_type: Design decision record
version: "0.1"
status: Draft
date: '2026-10-03'
author: Amish Chadha
license: CERN-OHL-S-2.0
revisions:
- version: "0.1"
  date: '2026-10-03'
  author: Amish Chadha
  change: "Amish's decisions 27A, 28B and 29B of 2026-10-03 recorded and carried out in the model, calculations, drawings and build plan"
---

# 0003: Requirement decisions of 2026-10-03 (R4, R3, R1)

- **Date:** 2026-10-03
- **Status:** accepted

## Context

The TRL 3 calculations (SKG-CAL-001 v0.1) left one requirement not met on paper and two at risk, each posed to Amish with options and a recommendation in the design decisions register (SKG-DEC-001, open decisions 1 to 3) and `docs/REVIEW.md`:

- **R4, cycle time:** about 3.7 min at 10 m against 3 min, because two people at the cranks give about 100 W and the hoist took 111 s.
- **R3, bite per cycle:** 21.2 L at an assumed 75 % fill but 14.1 L at 50 %, because the 2:1 tackle closed the lips with only 0.71 of the line pull, capped by the grab's submerged weight.
- **R1, depth gained:** the 8-ring string keeps sinking to 3 m only while skin friction stays below 1.66 kPa, against an estimate of 1 to 3 kPa.

These were items 27, 28 and 29 of the portfolio's round-2 list. Amish Chadha (owner), 2026-10-03: "i agree with all the 46 recommendations you provided. please proceed."

## Options considered

| Item | Option A | Option B | Option C |
| --- | --- | --- | --- |
| 27, R4 | **A third person at the cranks during the hoist, on a 240 mm two-hand handle (chosen)** | Narrower 240 mm shells: 3.4 min but a 15 L bite, so R3 missed | Keep two people and make 4 min the trial target |
| 28, R3 | Keep the 2:1 tackle and settle the fill in trials | **A 3:1 tackle with a second sheave in the head (chosen)** | 10 kg more head ballast: 14 % more lip force, shear link margin down to 1.08 |
| 29, R1 | Toes 15 mm past the ring as drawn; measure in the trial | **Toe blades cutting 40 mm past the ring's outer face (chosen)** | Sixteen saddles: limit 1.81 kPa for 165 kg more kit and USD 340 |

## Decision

All three as recommended:

1. **27A.** The +X crank carries a 32 x 240 mm handle on a longer M12 bolt so two people can work it side by side; a third person joins the hoist and the crew is two at other times. R4 is restated: "3 min or less per grab cycle at 10 m depth with three people at the cranks during the hoist and two otherwise" (SKG-REQ-001 v0.4).
2. **28B.** The closing line now runs down through the head's guide tube, under the crosshead sheave, up over a fourth bought sheave (the upper sheave) hung on two 6 mm cheeks under the head, and down to the shear link on a dead-end arm and lug welded to the crosshead. The upper sheave stands across the hinge direction so the line comes up into it on the grab's centre plane and leaves 130 mm to one side. The dead-end arm stays above 140 mm from the hinge so the open shells clear it.
3. **29B.** A 10 mm wear-resistant blade, 100 x 35 mm, is welded under the end of each scraper arm at the cutting level, lapped on the toe plate and standing 25 mm beyond it, so the blades cut 40 mm past a 1.0 m ring's outer face (first design 15 mm). The arm and its linkage are unchanged, so the fold is unchanged apart from the blade.

## Consequences

From SKG-CAL-001 v0.2 and `cad/src/model.py` (no overlaps, no parts adrift, folded scraper inside the smallest bore):

| Requirement | Before | After | Target | Status |
| --- | --- | --- | --- | --- |
| R4 cycle at 10 m | 3.7 min (two people) | 3.17 min with three at the hoist (3.8 min with two) | 3 min or less | Not met on paper by about 0.2 min (6 %); the timed trial decides |
| R3 bite | 21.2 L at 75 %, lips closing with about 437 N | 21.2 L at 75 %, lips closing with about 685 N (1.06 of the line pull, 50 % more) | At least 20 L | Met on paper at the assumed fill; the test-pit trial confirms the fill |
| R1 depth | Sinks while friction is below 1.66 kPa | Unchanged limit; blades cut 40 mm past the ring to keep friction low | At least 3 m | At risk; friction measured in the first trial |

- **Mass.** The grab rises from 47.9 to 51.0 kg (upper sheave 2.2 kg, axle, cheeks and dead-end arm), about 0.6 kg more than the 2.5 kg estimated when the option was posed. The cranks gain about 0.8 kg (the handle is modelled solid; a tube is lighter). The toe blades add about 0.4 kg, which takes the scraper head with its arms on to 25.2 kg, over the 25 kg limit of R9: it is carried with the arms unpinned (19.2 and 6.0 kg), and the heaviest piece is then the capstan frame at 22.9 kg. The kit is about 456 kg.
- **Overload limits.** Every part of the line carries the same tension, so the shear link still sees the line pull. Its lowest release is now 1.15 times the working pull (1.19 before), and the proof load at twice the working load is 193 kg, inside HatchSide's 225 kg. The crank pin limits are unchanged.
- **Cycle.** The 3:1 tackle takes 426 mm of line to close (284 before), about 1.5 s more a cycle, and its 3.1 kg slows the hoist by about 4 s; the third person saves about 39 s.
- **Scraper.** The T-bar force rises 4 % (142 N each for two people). Folded, the blades reach 389 mm radius, inside the 400 mm bore of a 0.8 m ring with 11 mm to spare. The soil to remove for 3 m of sinking rises from 3.28 to 3.56 m3.
- **Cost.** Value-engineering target: USD 4,000. Estimated cost of the constructable design: USD 2,561 (USD 1,439 under the target). The changes add USD 55: upper sheave USD 30 and cheeks, axle and dead-end arm USD 5 (USD 35 for the tackle), the long handle USD 10, the toe blades USD 10.
- **Safety.** Three people now stand at the capstan during the hoist. The briefing card and safety stop 4 say that all three let go together on the stop call, the pawl holds the drum, and nobody stands between the capstan and the lead sheave. The crank shear pin matters more with a third person, not less.
- **Finding while checking the fold.** The scraper's arms fold only if the sleeve can slide 300 mm down the pole, but the stop collar is drawn 40 mm below the sleeve, so as drawn the toes fold only to about 604 mm radius. This was true of the first design too. It is posed to Amish in SKG-DEC-001 and `docs/REVIEW.md`.
- **Changed files.** `cad/src/model.py`, `docs/04-calcs/sizing.py` and `01-sizing.md` (v0.2), `docs/03-requirements.md` (v0.4), `docs/02-concept.md` (v0.4), `docs/05-build-plan.md` (v0.2), `bom/bom.csv` (lines 4, 10, 13, 14, 15, 25), SKG-DWG-001 and 002 (Rev P3), SKG-DWG-103, 110, 111, 113, joints 9 and 14, steps 9, 13 and 20, the overview, concept media and `cad/src/product_model.py`.

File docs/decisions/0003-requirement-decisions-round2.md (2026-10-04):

---
doc_id: SKG-DDR-003
title: SinkGrab requirement decisions, round 2
project: SinkGrab
doc_type: Design decision record
version: "0.1"
status: Draft
date: '2026-10-03'
author: Amish Chadha
license: CERN-OHL-S-2.0
revisions:
- version: "0.1"
  date: '2026-10-03'
  author: Amish Chadha
  change: Amish's decisions on R4 (1A), R3 (2B) and R1 (3B) carried into the model, calculations, BOM, drawings and build plan
---

# 0003: Requirement decisions, round 2

- **Date:** 2026-10-03
- **Status:** Decided by Amish Chadha, 2026-10-03: "i approve all of the 47 recommendations provided by you. Execute them." For SinkGrab these are the three requirement decisions of SKG-DEC-001 (portfolio decisions 31, 32 and 33), each decided as recommended.

## Context

At TRL 3 (SKG-CAL-001 v0.1) the constructable design (SKG-DDR-002) missed R4, a 3 min cycle at 10 m, at about 3.7 min, because two people at the cranks give about 100 W and the hoist took 111 s. R3, at least 20 L a bite, was at risk: the lips closed with only about 0.71 of the line pull through the 2:1 tackle, and the line can pull no more than the grab's submerged weight. R1, 3 m of depth gained below the water table, was at risk: the 8-ring string keeps sinking only while skin friction stays below 1.66 kPa, against an estimate of 1 to 3 kPa. The three were put to Amish with options and a recommendation in `docs/REVIEW.md` and SKG-DEC-001.

## Options considered

*Table 1. The three decisions put to Amish and the option chosen.*

| # | Requirement | Options | Chosen |
| --- | --- | --- | --- |
| 1 | R4, cycle time | A: a third person at the cranks during the hoist with a 240 mm two-hand handle. B: narrower 240 mm shells (bite about 15 L, R3 not met). C: keep two people and make 4 min the trial target | **A** |
| 2 | R3, bite per cycle | A: keep the 2:1 tackle and settle the fill in test-pit trials. B: a 3:1 tackle with a second sheave in the head. C: 10 kg more ballast on the head | **B** |
| 3 | R1, depth gained | A: as designed, measure friction in the first trial. B: longer toes cutting 40 mm past the ring's outer face. C: sixteen saddles instead of eight | **B** |

## Decision

*Table 2. Each decision as carried into the design. Figures from SKG-CAL-001 v0.2 (`docs/04-calcs/sizing.py`).*

| # | Requirement | Option chosen | Effect on the design | Condition |
| --- | --- | --- | --- | --- |
| 1 | R4 | A: third person at the cranks for the hoist | The +X crank carries a 32 mm handle 240 mm long for two hands (the -X crank keeps its 120 mm handle). Three people at 50 W hoist the full grab at 8.7 m/min; the hoist takes 77 s and the cycle 3.16 min, 5 % over the 3 min target. With two people it is 3.8 min. BOM line 4, USD 10 more | R4 stays **not met on paper**, within 5 %; the timed trial settles the last 0.16 min. R4 is worded for two operators; restating it is a new question (`docs/REVIEW.md`) |
| 2 | R3 | B: 3:1 closing tackle | A second bought 150 mm sheave hangs under the head box between two 8 mm cheeks on a 20 mm axle, skewed 20 degrees about the vertical so both of its rope parts hang straight; the dead end and the shear link move from the head to a 12 mm lug on the crosshead's -Y plate. The line now runs down the guide tube, under the crosshead sheave, up over the head sheave and down to the shear link. Mean lip force rises from 0.71 to 1.06 of the line pull: about 687 N at the lips, 50 % more. Closing takes 426 mm of line, about 1 s more a cycle. The grab gains 3.3 kg (estimate 2.5 kg) to 51.2 kg; the working pull rises to 1,042 N, the shear link's margin falls from 1.19 to 1.15 and the line factor from 10.7 to 10.4. BOM lines 10, 13, 14 and 25: USD 35 more | R3 stays **at risk**: the fill is still an assumption (21.2 L at 75 %, 14.1 L at 50 %) and is settled in the TRL 4 test-pit bite trial; the stronger close makes the higher fill more likely |
| 3 | R1 | B: toes cutting 40 mm past the ring | Arms 25 mm longer (564 mm pivot to toe); the toes reach 615 mm radius, 40 mm past a 1.0 m ring's outer face (was 15 mm). Two people need 142 N each on the T-bar, 4 % more. The soil removed for 3 m of sinking rises to about 3.56 m³. BOM line 15, USD 10 more | R1 stays **at risk**: the friction limit is still 1.66 kPa and the friction itself is only measured in a trial; the wider cut is meant to keep it toward the low end of the 1 to 3 kPa estimate |

*Table 3. Change made while carrying out decision 3, to keep the design constructable (STANDARDS section 18).*

| # | Change | Why |
| --- | --- | --- |
| 4 | Fold lift 320 mm (was 300 mm) | With the longer arms a 300 mm lift folds the toes to 405.5 mm radius, outside the 400 mm bore of the smallest (0.8 m) ring; a 320 mm lift folds them to 377 mm. The model's constructability check passes again. This does not change what the scraper does |

## Consequences

- `cad/src/model.py` carries the changes (`handle_long`, `tackle_parts`, `head_sheave_skew`, `head_sheave_z`, `toe_r` 615, `fold_lift` 320, new parts `upper_sheave` and `upper_axle`); the checks report no overlaps and no floating parts.
- SKG-CAL-001 v0.2 is re-run: R4 3.16 min (not met on paper, within 5 %); R3 at risk with 687 N at the lips; R1 at risk; R9 now **not met on paper by 0.1 kg**, because the longer arms bring the scraper head to 25.1 kg against the 25 kg limit (a new question in `docs/REVIEW.md`).
- Estimated cost of the constructable design: USD 2,561 (was USD 2,506), USD 1,439 under the USD 4,000 value-engineering target; `budget_usd` unchanged.
- STEP and STL, SKG-DWG-001 and 002 (Rev P3), the concept media, `media/model.glb` and the build plan pictures and making sketches are regenerated from the model. The photoreal renders made on Amish's Mac predate this change.
- New questions raised while carrying out the decisions (scraper fold travel and the 25 kg piece limit, R4 wording, shear link margin) are recorded in `docs/REVIEW.md` and SKG-DEC-001 as **Proposed, awaiting Amish**.

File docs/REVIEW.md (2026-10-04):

# Review note: SinkGrab

## Session 2026-10-04: Amish's requirement decisions carried out (round 3)

Amish Chadha (owner), 2026-10-04: "For round 3, I agree with all your proposed recommendations". For SinkGrab that decides item 5A, open decision 4 of SKG-DEC-001 (scraper sleeve travel), as recommended. Recorded in `docs/decisions/0004-scraper-sleeve-travel.md` (SKG-DDR-004) and moved to Decisions made in `docs/06-design-decisions.md` (SKG-DEC-001 v0.3). Nothing was committed or pushed.

### Changes made and new results

| Item | Change | New result | Target |
| --- | --- | --- | --- |
| 5A, R2 | The stop collar is gone. The sleeve is 340 mm long (top 15 mm below the hub) with a 13 x 312 mm slot each side; a 12 mm cross pin, 70 mm long with an R-clip, passes through the slots and a 12.5 mm hole in the pole 140 mm above the tip. Strut lugs stay where they were, so the linkage is unchanged | Sleeve travel 300 mm (about 40 mm before); arms fold to 389 mm radius (about 604 mm as previously drawn), 11 mm inside a 0.8 m ring's bore; spike still 110 mm below the foot. Pin 6 MPa in double shear with the whole 25 m string on the foot (factor 43) | Rings of 0.8 to 1.3 m: **met by design** |
| Knock-on, R9 | Scraper head 26.1 kg with arms on, 20.1 kg with them unpinned (25.2 and 19.2 before) | Heaviest piece still the capstan frame, 22.9 kg; kit about 457 kg | 25 kg or less: met on paper |
| Knock-on, R11 | BOM line 15 rises USD 5 (USD 70 to 75) | USD 2,566 | Met on paper, within the target |

No requirement is restated; SKG-REQ-001 v0.5 updates the status of R2, R9 and R11 only. The model gains a fold check: the sleeve slid 300 mm down the pole is held by the cross pin at its slot tops without touching the pole, and the folded toes are inside the smallest bore. All constructability checks pass (no overlaps, no parts adrift, fold check clear). The net mass is 0.9 kg (sleeve +1.1 kg, pin +0.06 kg, collar -0.3 kg), less than the 1.4 kg estimated when the option was posed.

**Cost and mass.** Value-engineering target: USD 4,000. Estimated cost of the constructable design: USD 2,566 (USD 1,434 under the target). The change adds USD 5 (230 mm more 54 mm tube, two slots, a 12 mm bright bar pin and R-clip; the collar is dropped). `budget_usd` unchanged.

**Files.** `cad/src/model.py` (longer slotted sleeve, new part `cross_pin`, stop collar removed, cross hole in the pole, fold check); STEP and STL regenerated; `bom/bom.csv` (line 15, with its price basis); `docs/04-calcs/sizing.py`, `01-sizing.md` (v0.3, new H7 and H8) and `results.csv`; `docs/03-requirements.md` (v0.5); `docs/02-concept.md` (v0.5); `docs/05-build-plan.md` (v0.3: making steps for the pole and sleeve, joint 10 and 14 captions, step 14, the scraper check); `README.md` (cost); `docs/decisions/0004-scraper-sleeve-travel.md`; `docs/06-design-decisions.md`.

**Pictures.** SKG-DWG-002 to Rev P4; making sketches SKG-DWG-112 and 113 to Rev P2; joints 10 and 14; steps 14 and 15; the overview; concept media (hero, exploded, blueprint, flow, `model.glb`); `cad/src/product_model.py` and the exported render scenes in `/home/claude/renders/sinkgrab` (hero, exploded, detail). The photoreal renders on Amish's Mac predate the change and show the short sleeve and collar in the detail view; they need re-rendering there.

### Open decisions

None. No new question came out of this change.

### Cross-repo actions

None. No other repo quotes SinkGrab's scraper.

### Safety concerns

- No change to the safety case. With the sleeve able to fold the arms, the scraper no longer jams under the ring as drawn; nobody enters the well to free anything.
- If the cross pin is missing, the sleeve and foot drop off the pole when it is lifted. The pin and its R-clip are checked at every pole change.

### Recommended next step

All decisions are made. The design is ready for TRL 4 when the phase allows, as recommended before: build and proof-load the capstan, cradle and grab on CalRig, break-test the link and crank pins, check the scraper's fold through a 0.8 m ring on the ground, then run the test-pit bite trial and the timed three-person cycle trial before a partner well.

## Session 2026-10-03: Amish's requirement decisions carried out (round 2)

Amish Chadha (owner), 2026-10-03: "i agree with all the 46 recommendations you provided. please proceed." For SinkGrab that decides items 27A, 28B and 29B (open decisions 1 to 3 of SKG-DEC-001), each as recommended. Recorded in `docs/decisions/0003-round-2-requirement-decisions.md` (SKG-DDR-003) and moved to Decisions made in `docs/06-design-decisions.md` (SKG-DEC-001 v0.2). Nothing was committed or pushed.

### Changes made and new results

| Item | Change | New result | Target |
| --- | --- | --- | --- |
| 27A, R4 | A 32 x 240 mm two-hand handle on the +X crank so a third person joins the hoist; R4 restated in SKG-REQ-001 v0.4 as "3 min or less per grab cycle at 10 m depth with three people at the cranks during the hoist and two otherwise" | 3.17 min (hoist 76 s); 3.8 min with two | 3 min: **not met on paper by about 0.2 min (6 %)**; the timed trial decides |
| 28B, R3 | 3:1 closing tackle: an upper sheave (fourth bought sheave) on 6 mm cheeks under the head, turned across the hinge; the dead end and shear link moved to a 10 mm arm and lug on the crosshead, kept above 140 mm so the open shells clear it | Lips close with about 685 N, 1.06 of the line pull (457 N and 0.71 before, +50 %); bite 21.2 L at the assumed 75 % fill | At least 20 L: met on paper at the assumed fill; the test-pit trial confirms the fill |
| 29B, R1 | A 100 x 35 x 10 mm wear-resistant blade under each toe, 25 mm beyond the toe plate, cutting 40 mm past a 1.0 m ring's outer face (15 mm before) | Sinking limit still 1.66 kPa of skin friction (estimate 1 to 3); the cut loosens the soil against the ring; T-bar force +4 % (142 N each) | At least 3 m: **at risk**; friction measured in the first trial |

Knock-on results (SKG-CAL-001 v0.2): grab 51.0 kg (47.9 before; the tackle adds 3.1 kg, about 0.6 kg more than the 2.5 kg estimated when the option was posed), 96 kg full; working pull 1,041 N; shear link margin 1.15 (1.19 before); proof at twice the working load 193 kg, inside HatchSide's 225 kg; crank force 54 N each for two; line factor 10.4. Folded toe radius 389 mm, inside the 400 mm bore of a 0.8 m ring. The scraper head with its arms on is 25.2 kg, over R9's 25 kg, so it is carried with the arms unpinned (19.2 and 6.0 kg); the heaviest piece is then the capstan frame, 22.9 kg, and R9 stays met. Kit about 456 kg.

**Cost and mass.** Value-engineering target: USD 4,000. Estimated cost of the constructable design: USD 2,561 (USD 1,439 under the target). The changes add USD 55: tackle USD 35 (sheave USD 30; cheeks, axle and dead-end arm USD 5), long handle USD 10, toe blades USD 10. `budget_usd` unchanged.

**Files.** `cad/src/model.py` (new parts `upper_sheave`, `upper_axle`; cheeks in `head`; dead-end arm in `crosshead`; `toe_ext`; long handle; checks for the new parts: no overlaps, no parts adrift); STEP and STL regenerated; `bom/bom.csv` (lines 4, 10, 13, 14, 15, 25, each with a price basis); `docs/04-calcs/sizing.py`, `01-sizing.md` (v0.2) and `results.csv`; `docs/03-requirements.md` (v0.4); `docs/02-concept.md` (v0.4); `docs/05-build-plan.md` (v0.2); `README.md` (cost and one sentence).

**Pictures.** SKG-DWG-001 and 002 to Rev P3; making sketches SKG-DWG-103 (cranks), 110 (head), 111 (crosshead and link), 113 (arms and blades); joint 9 (now the upper sheave and shear link) and joint 14 (blade past the ring); steps 9, 13 and 20; the overview; concept media (hero, exploded, blueprint, flow, `model.glb`); `cad/src/product_model.py` and the exported render scenes in `/home/claude/renders/sinkgrab` (hero, exploded, detail).

### Decision for Amish

**4. Scraper sleeve travel (R2), found while carrying out 29B.**
- *State:* the scraper's arms fold to pass the ring bore only when the sliding sleeve moves 300 mm down the pole (folded radius 389 mm). As drawn, the stop collar sits 40 mm below the sleeve and the pole ends 120 mm below it, so the sleeve can slide only about 40 mm and the toes fold only to about 604 mm radius: the head could not be lifted out through any ring in the range. The first design had the same fault; the build plan's step 14 and joint 10 show it.
- *Option A:* lengthen the sleeve to about 340 mm (top just below the hub) with a 300 mm slot each side, and put a 12 mm cross pin through the pole that runs in the slots and stops the sleeve at full fold; the stop collar goes and the spike stays 110 mm below the foot. About USD 5 and 1.4 kg; the head with its arms unpinned becomes about 20.6 kg.
- *Option B:* lengthen the bottom pole and spike 320 mm and move the stop collar down. The spike end then stands about 430 mm below the foot when working and has to be pushed that far into the sump floor before the arms open. About USD 3 and 0.6 kg.
- **Recommendation: A.** Nothing has to be forced into the sump floor, the 330 mm sump limit keeps its meaning, and the linkage, struts and fold radius stay as calculated.

### Cross-repo actions

None. No other repo quotes SinkGrab's tackle, proof load or scraper; the upper sheave is the same bought sheave as the other three.

### Safety concerns

- Three people stand at the capstan during the hoist. Safety stop 4 now says all three let go together on the stop call, the pawl holds the drum, and nobody stands between the capstan and the lead sheave. The crank shear pin matters more with a third person.
- The shear link's margin over the working pull falls to 1.15; a link pin that releases low will open the grab more often, which is safe but slow. Break-testing the pins (To confirm, item 1) stays essential.
- Until decision 4 is made, the scraper as drawn could jam under the ring; nobody enters the well to free it.

### Recommended next step

Amish decides item 4. The design is then ready for TRL 4 when the phase allows, as recommended before: build and proof-load the capstan, cradle and grab on CalRig, break-test the link and crank pins, then run the test-pit bite trial and the timed three-person cycle trial before a partner well.

## Session 2026-10-03: TRL 3 (kit 1.7.0, /to-trl3 under Amish's pre-approvals, batch 2)

Amish, 2026-10-03: "start with the first 14 repos from the list of 29 projects. I pre-approve the batch runs along with any recommendations you come up with. I also accept any cost overruns or variations from the assumed scope cost." Then, the same day: "Proceed with the remaining 15 scaffolds", under the same pre-approval; SinkGrab is in that batch. Design choices and recommendations in this session are therefore recorded as decided, dated 2026-10-03, in `docs/06-design-decisions.md`. Requirements that are not met or at risk are not decided here (Amish, 2026-10-03: "A simple statement doesn't add value - ensure you are identifying a state and posing it as a clear recommendation for me to decide on."); they are posed below under "Decisions for Amish". Kit 1.7.0 was installed from the kit source; `.kit/PHASE.yaml` kept as installed. Nothing was committed or pushed.

### TRL 2

**What was done.**

- `docs/01-problem.md` (SKG-PRB-001 v0.2): first co-design candidates, safety section, the scaffold's open questions answered and replaced by questions for the first trials; budget restated as a value-engineering target.
- `docs/03-requirements.md` (SKG-REQ-001 v0.2): concept status for every requirement; R11 restated against the value-engineering target.
- `docs/02-concept.md` (SKG-PRC-001 v0.2): how it works, components, key design choices, safety.
- `docs/decisions/0001-trl2-review-decisions.md` (SKG-DDR-001): fifteen TRL 2 review items decided.

**Results.** On first-order numbers one hand capstan and one rope can dig, lift and dump a grab of about 20 L, the HatchSide tripod's 150 kg rating is the binding limit on the line, and a pole is the only practical way to turn a scraper at depth.

**Requirements not met.** None identified at TRL 2; cycle time was flagged as the tightest.

**Decisions made under the pre-approvals.** SKG-DDR-001, items 1 to 15: two-shell clamshell; one closing line with a head that opens the shells by weight; shear link and crank shear pin (conservative); SinkGrab hand capstan in place of the HatchSide winch; drawbar to a cradle under the leg A foot (conservative); lowering on a weighted band brake with the cranks off (conservative); centred scraper pole with weight-opened arms; no de-watering and a 330 mm sump limit (conservative); tilt read every cycle, correct from 1 in 160, stop at 1 in 80 (conservative); ballast saddles; well-head doors and tubs in place of a chute (conservative); Kerala Ground Water Department as first co-design candidate, Ethiopian highlands NGO second (neither agreed); shared blocks (HatchSide with an 8 mm head sheave, single-drum capstan variant, CalRig); patent search before release; budget kept.

**Safety concerns.** Falls into the shaft; loads dropping into the well; bad air; overload of a tripod rated for material handling only; rings dropping or tilting when undercut.

### TRL 3

**What was done.**

- `docs/04-calcs/01-sizing.md` and `docs/04-calcs/sizing.py` (SKG-CAL-001 v0.1), `docs/04-calcs/results.csv`.
- `cad/src/model.py`: parametric build123d model with constructability checks (no overlaps, no floating parts, folded scraper passes the smallest bore); STEP and STL in `cad/step` and `cad/stl` (capstan, lead, grab, scraper, well-head, saddle; assembly STEP).
- `cad/src/sheets.py`: SKG-DWG-001 (well-head layout) and SKG-DWG-002 (grab and scraper GA), Rev P2.
- `bom/bom.csv`: 34 lines, all priced, suppliers by type.
- `cad/src/concept_media.py`: `media/hero.png`, `exploded.png`, `flow.png`, `concept-blueprint.png` and `.pdf` (SKG-DWG-010), `model.glb` (coarse tessellation) and `viewer.html`. No cutaway; the inside of the well is shown in the detail render and build plan joint 14.
- `docs/decisions/0002-design-for-construction.md` (SKG-DDR-002); `design_state: constructable`.
- `cad/src/build_plan_media.py`: overview, 17 making sketches (SKG-DWG-101 to 117), 14 joint close-ups and 20 step pictures; `docs/05-build-plan.md` (SKG-BLD-001) and `docs/06-design-decisions.md` (SKG-DEC-001).
- `cad/src/product_model.py` (`product_parts()`, `TITLE`, `RENDER_VIEWS` hero, exploded, detail); scenes exported to `/home/claude/renders/sinkgrab`. Photoreal renders, captions and cards are made on Amish's Mac; the README already leads with `media/render-hero.png`.
- `docs/01-problem.md`, `docs/02-concept.md` (v0.3), `docs/03-requirements.md` (v0.3), `README.md`, `project.yaml` (trl 3, trl_target 3).

**Results (SKG-CAL-001).** Bite 21.2 L at 75 % fill (28.3 L closed); grab 47.9 kg, 93 kg full; working line pull 1,006 N; 52 N on each crank with two people; hoist 6.0 m/min; shear link releases 1,202 to 1,469 N, inside the tripod's 1,472 N rating; crank pin caps the line at 2,107 N, inside its 2,207 N proof load; line factor 10.7; brake 314 N m (factor 1.69 at the limit); scraper 136 N each on the T-bar, working limit 25 m; arms fold to 364 mm radius; heaviest piece 24.6 kg; kit about 452 kg. Value-engineering target: USD 4,000. Estimated cost of the constructable design: USD 2,506 (USD 1,494 under the target).

**Requirements not met or at risk.** R4 not met on paper (3.7 min); R3 at risk (fill); R1 at risk (skin friction). R6 can only be verified in a trial. Each of R4, R3 and R1 is posed below.

#### Decisions for Amish

**1. R4, cycle time (not met on paper).**
- *State:* about 3.7 min a cycle at 10 m with two people at the cranks. Cause: two people give about 100 W, so hoisting the full 93 kg grab 11 m takes 111 s, half the cycle; gearing cannot change this.
- *Option A:* a third person at the cranks during the hoist, on one crank with a 240 mm two-hand handle. Cycle about 3.1 min; cost about USD 10; mass about 0.5 kg. The problem statement's crews are three to five people.
- *Option B:* narrower shells, 240 mm wide. Cycle about 3.4 min; bite falls to about 15 L, so R3 is not met; cost about USD 10 less; mass about 4 kg less.
- *Option C:* keep two people and make 4 min the trial target. Cycle 3.7 min; no cost or mass change.
- **Recommendation: A.** It keeps the full bite and brings the cycle within about 5 % of the target with people the crew already has; the timed trial settles the last 0.1 min.

**2. R3, bite per cycle (at risk).**
- *State:* 21.2 L at an assumed 75 % fill; 14.1 L if the fill is 50 % in denser sand. Cause: through the 2:1 tackle the lips close with 0.71 of the line pull, and the line can pull no more than the grab's 618 N submerged weight before it lifts, so the lips close with only about 437 N.
- *Option A:* keep the 2:1 tackle and settle the fill in test-pit trials. No change to cost, mass or cycle.
- *Option B:* a 3:1 tackle, with a second sheave in the head. Lip force about 656 N (+50 %); about 1.5 s more a cycle; cost about USD 35; mass about 2.5 kg.
- *Option C:* 10 kg more ballast on the head. Lip force about 14 % more; working pull rises to about 1,114 N and the shear link's margin falls from 1.19 to 1.08; cost about USD 10; mass 10 kg.
- **Recommendation: B.** It raises the closing force most for the least mass and leaves the link margin unchanged.

**3. R1, depth gained below the water table (at risk).**
- *State:* the 8-ring string (16.4 kN effective) with eight saddles (1.6 kN) keeps sinking to 3 m only while skin friction stays below 1.66 kPa; the estimate for loose saturated sand is 1 to 3 kPa. Cause: the rings' own weight is the only driving force without pumps or jacks, and the saddles add 10 %.
- *Option A:* as designed (toes 15 mm past the ring's outer face) and measure friction in the first trial. No change.
- *Option B:* longer toes that cut 40 mm past the ring's outer face, loosening the soil against the ring so friction stays toward the low end of the range. T-bar force about 4 % more; cost about USD 10; mass about 0.5 kg.
- *Option C:* sixteen saddles instead of eight. The limit rises to 1.81 kPa; cost about USD 340 with lines; kit 165 kg heavier.
- **Recommendation: B.** It acts on the friction itself at almost no cost; C buys little for its weight.

**Decisions made under the pre-approvals.** SKG-DDR-002, the fifteen design-for-construction changes listed below; the scraper's 25 m working limit; the appearance model additions (below). All in `docs/06-design-decisions.md`.

**Build plan findings (design changes made for construction, SKG-DDR-002).**

1. Ground capstan 3.0 m from a lead sheave in a cradle under the leg A foot, joined by a drawbar; the HatchSide tripod sees its own winch load case.
2. A 150 mm head sheave grooved for the 8 mm line replaces HatchSide's wire-rope sheave while SinkGrab works.
3. Capstan frame in 40 x 40 x 2 tube: 22.9 kg (first model 32 kg).
4. Drum flanges and brake web 6 mm with lightening holes: 18.3 kg.
5. Pawl pivot moved behind the nose so its body clears the teeth.
6. Weighted band brake detailed; anchor and link separated.
7. Stake tubes and guard tabs moved to clear the braces and guard.
8. Grab lightened from 72 to 47.9 kg so the shear link keeps a 1.19 margin.
9. Interleaved hinge: shell B's end plates outside shell A's.
10. Shear link at the tackle dead end with a calibrated pin.
11. Scraper arms pinned to the hub and opened by struts from a sliding sleeve; fold to 364 mm.
12. Pole in 2.0 m sections with spigots and M12 bolts; T-bar socket and eye.
13. Well-head frame with two mesh doors, pole hole and datum brackets in place of a chute.
14. Eight U-saddles on their own lines in place of a ballast frame.
15. Pin holes 0.25 to 0.5 mm over the pin so each part rests on what holds it.

**Appearance model.** `product_model.py` uses the `model.py` solids. Additions not in `model.py`: the wound rope on the drum, the context collar, ground disc, spoil tub, cut-away ring pieces and a 1.75 m mannequin (`mannequin()`, standing at the -X crank facing the capstan, beside the kit and not between the camera and it). Decided under the pre-approvals.

**Safety concerns.**

- The HatchSide tripod is rated 150 kg for material handling. The shear link holds the grab to it; the crank pin caps any snag below its proof load. A link or crank pin replaced by a bolt removes both limits; the briefing card and safety stop 6 say so.
- The line jammed in a sheave (above the link) is limited only by the crank pin, up to 2.1 kN, which is inside the tripod's proof load but over its rating; stop 6 (find the snag with the line slack) covers it.
- Lowering depends on the brake weight; the cranks are removed so nothing spins if it slips.
- Undercutting can drop or tilt the rings; the sump limit and tilt stops are conservative and need trial data.
- Bad air: the gas detector is a bought item; its use is a stop, not a design feature.
- Nobody enters the well; any entry is a separate operation with its own equipment.

**Recommended next step.** After Amish decides R4, R3 and R1, the design is ready for TRL 4 when the phase allows: build the capstan, cradle and grab, proof-load them on CalRig with the HatchSide tripod, break-test the link and crank pins, then run the test-pit bite trial and the timed cycle trial before a partner well. Suggestion not added to the repo: an automatic load brake (Weston type) bought in would let the crew lower on the cranks and save about 20 s a cycle.

## Session 2026-09-30: scaffolded

### What was done

- Repository created from kit 1.6.0 at TRL 1, target TRL 2.
- `docs/01-problem.md` (SKG-PRB-001 v0.1): problem with cited evidence, users, environment, constraints, prior work, open questions.
- `docs/02-concept.md` (SKG-PRC-001 v0.1): how it works, components, patent design-arounds, shared blocks, safety.
- `docs/03-requirements.md` (SKG-REQ-001 v0.1): 11 proposed requirements.
- `README.md` with concept rationale, burning platform, where it could be used, and what sparked the idea.

### Next

- Run `/populate` to bring the repo to a strong TRL 2 with concept media.

## 2026-10-03: photoreal renders

Rendered with Blender Cycles on Amish's Mac from `cad/src/product_model.py`; captioned with `.kit/photo_caption.py`; `media/card.png` and `media/social-preview.png` made with `.kit/cards.py`. Views: hero, exploded, detail. image_qc passes and `render.py --check` has no FAIL.

## 2026-10-04: photoreal renders redone after the round-2 and round-3 decisions

Views: hero, exploded, detail; cards regenerated; image_qc passes and `render.py --check` has no FAIL.

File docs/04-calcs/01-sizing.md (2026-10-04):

---
doc_id: SKG-CAL-001
title: SinkGrab sizing calculations
project: SinkGrab
doc_type: Calculation
version: "0.3"
status: Draft
date: '2026-10-04'
author: Amish Chadha
license: CERN-OHL-S-2.0
revisions:
- version: "0.1"
  date: '2026-10-03'
  author: Amish Chadha
  change: First issue for TRL 3 on the constructable design (SKG-DDR-002); grab capacity and closing force, overload limits, crank force and speed, drum and rope, brake, tripod and drawbar, scraper, sinking and tilt, cycle time, masses and cost
- version: "0.2"
  date: '2026-10-03'
  author: Amish Chadha
  change: "Amish's round-2 decisions of 2026-10-03 (\"i agree with all the 46 recommendations you provided. please proceed.\"): 27A third person on the cranks during the hoist, 28B 3:1 closing tackle, 29B toe blades cutting 40 mm past the ring's outer face (SKG-DDR-003); every section re-run"
- version: "0.3"
  date: '2026-10-04'
  author: Amish Chadha
  change: "Amish's round-3 decision 5A of 2026-10-04 (\"For round 3, I agree with all your proposed recommendations\"): 340 mm slotted sleeve on a 12 mm cross pin so the scraper arms fold to pass the ring (SKG-DDR-004); sections H and K re-run, H7 and H8 added"
---

# SinkGrab sizing calculations

On paper SinkGrab does what it was drawn for, inside the HatchSide tripod's rating, and after Amish's round-2 decisions of 2026-10-03 it comes within about 0.2 min of its 3 min cycle-time target. The grab lifts 21 L of saturated sand a bite at an assumed 75 % fill, now closed by a 3:1 tackle that presses the lips 50 % harder than the first design's 2:1; two people hoist the full 96 kg grab with 54 N each on the cranks, and a third person on a long two-hand handle joins them for the hoist; a shear link and a crank shear pin keep the line below the tripod's 150 kg rating and 225 kg proof load whatever the crew does; the toes now cut 40 mm past the ring's outer face, and since Amish's round-3 decision of 2026-10-04 the scraper's sleeve slides the full 300 mm its arms need to fold through the ring; and the heaviest piece is 22.9 kg once the scraper's arms are unpinned for carrying. The parts cost USD 2,566 against a value-engineering target of USD 4,000. R4 is still not met on paper: a cycle at 10 m takes about 3.2 min (3.17 min) with three people at the hoist, 6 % over the target, and the timed trial decides it. R1 stays at risk, because the rings keep sinking to 3 m only while skin friction stays below about 1.7 kPa; the wider cut acts on that friction but only a trial can measure it. R3 is met on paper at the assumed fill, which the test-pit trial confirms. Every number here is printed by `docs/04-calcs/sizing.py`; the tag in brackets, for example [C2], is the line of that script's output that carries it.

> **Safety:** SinkGrab is lifting equipment over an open well shaft. These are first-principles estimates for a paper proof of concept; they do not show that any part is safe. Every lifting part must be proof-loaded before use (SKG-BLD-001, section 6), nobody stands under the grab or beside a loaded line, and nobody enters the well. A third person at the cranks means three people beside the capstan during the hoist; all three let go together on the stop call, and nobody stands between the capstan and the lead sheave. See SKG-PRC-001, Safety.

## Scope and method

The note checks every requirement in SKG-REQ-001 v0.4 against the design in SKG-PRC-001, as changed by SKG-DDR-003 and SKG-DDR-004, and the parametric model `cad/src/model.py`. The script imports the model's `PARAMS`, `derived()` and `masses()`, so the grab, drum, scraper and frame used here are the ones in the STEP files and drawings SKG-DWG-001 and 002. It also reads `bom/bom.csv` and `budget_usd` in `project.yaml`, and writes `docs/04-calcs/results.csv`.

The design case is a 1.0 m caisson ring with a 75 mm wall inside a 1.3 m lining, the digging face 10 m below ground (R4) and 3 m of water standing over it at the end of the work (R1). The HatchSide tripod stands over the well with SinkGrab's line in place of its winch.

## Assumptions

*Table 1. Main assumptions.*

| Area | Assumption | Basis |
| --- | --- | --- |
| Sand | Saturated fine to medium sand 2.0 kg/L (1.0 kg/L submerged); 3 L of water still in the grab out of the water | Handbook ranges |
| Bite | Shells fill to 75 % in loose saturated sand (range 50 to 90 %) | Estimate; settled only in test-pit trials |
| Hoisting | 1.1 dynamic allowance; 50 W per person sustained at a crank, the third person included; a 400 N short heave | Ergonomic ranges |
| Pins | S235 bar or mild steel wire, ultimate shear strength 240 MPa; crank pin scatter ±20 %; link pins break-tested from one coil, ±10 % | 0.6 times 400 MPa tensile |
| Tripod | HatchSide: 150 kg safe working load for material handling; proof 1.5 times | HTS-CAL-001 |
| Rope | 8 mm polyester double braid, 12 kN minimum breaking strength; eye splice keeps 90 % | Typical catalogue figures |
| Drive | Chain 95 %, each bearing 98 % | Typical figures |
| Brake | Lining on steel, friction 0.35; 270 degree wrap | Typical figures |
| Rings | Precast concrete 2,400 kg/m3; string of 8 rings, 6 under water; skin friction 1 to 3 kPa in loose saturated sand disturbed by the undercut | Estimate; no published figure for small well rings |
| Scraper | 150 N per toe cutting a 25 mm bite of loose saturated sand | Estimate |
| Cycle | Lowering on the brake at 0.5 m/s; cranks off and on 20 s; opening 10 s; closing 16.5 s (15 s plus 1.5 s for the extra line of the 3:1 tackle); doors and dumping 45 s | Estimates |
| Tape | One dip-tape reading at depth ±3 mm | Estimate |

## A. Grab capacity and mass (R3, R9)

The closed shells, 230 mm in radius and 340 mm wide, hold 28.3 L; at a 75 % fill a bite is 21.2 L [A1]. The grab weighs 51.0 kg: the shells 11.6 and 11.8 kg, the head 8.2 kg with 5.3 kg of ballast plates, the tie rods 3.8 kg; the 3:1 tackle (upper sheave, its axle and cheeks, and the dead-end arm on the crosshead) adds 3.1 kg to the first design's 47.9 kg [A2]. Full and out of the water it is 96.4 kg (946 N) [A3]; under water 65.7 kg (645 N) [A4]. With the 1.1 allowance the working line pull is 1,041 N [A5].

## B. Closing force (R3)

The line now runs down through the head's guide tube, under the crosshead sheave, up over the upper sheave in the head and down to the shear link on the crosshead: three parts between head and crosshead (Amish's decision 28B). Closing moves the crosshead 142 mm toward the head, which takes 426 mm of line, while the lips travel 401 mm in all; opened, the lips are 352 mm apart [B1]. The mean force at the lips is therefore 1.06 of the line pull. The line can pull no more than the grab's submerged weight, 645 N, before the grab lifts off the bottom, so the lips close with about 685 N, 1,007 N per metre of lip [B2]. The first design's 2:1 tackle gave 0.71 of the line pull, about 457 N, so the 3:1 tackle closes 50 % harder; the head weighs 13.5 kg with its plates and cheeks, which is what opens the shells [B3]. If the fill falls to 50 % in denser sand, a bite is 14.1 L [B4]. **R3 is met on paper at the assumed 75 % fill**; the harder close makes that fill more likely in denser sand, and the test-pit trial confirms it.

## C. Overload limits (R7)

A 3 mm S235 pin across the 25 mm crank shaft releases at 42.4 N m [C1]. Through the 4:1 chain that is a line pull of 1,756 N on the innermost layer of rope, 1,610 N on the second and 1,486 N on the third; with ±20 % scatter the pin releases between 1,189 and 2,107 N [C2]. The HatchSide tripod's safe working load is 1,472 N and its proof load 2,207 N, so the crank pin never lets the line pass the proof load [C3]. Without the pin, two people heaving 400 N each could put 8,280 N into a snagged line [C6]; a third person on the long handle makes the pin more necessary, not less.

The shear link at the tackle's dead end, now on the crosshead, is the precise limit. Every part of the line carries the same tension, so the link still sees the line pull. A pin of about 1.88 mm in double shear releases at 1,335 N nominal; break-tested pins from one coil, ±10 %, release between 1,202 and 1,469 N, inside the tripod's 1,472 N rating [C4]. Its lowest release is 1.15 times the working pull (1.19 before the 3.1 kg of tackle) [C5]. When it releases, the line runs free through both sheaves and the grab opens on the bottom; it is recovered on the recovery line.

## D. Crank force and speed (R5)

At the rated grab load on the third layer, one person pushes 108 N on a 250 mm crank and two people 54 N each [D1]. **R5 is met on paper.** Two people at 50 W each hoist the full grab at 5.8 m/min, cranking at about 38 rpm [D2].

## E. Drum and rope (R7)

The drum holds 23 turns a layer: 12.7, 13.9 and 15.1 m in three layers, 41.7 m, against the 38.7 m a 30 m well needs [E1]; the 3:1 tackle takes about 0.4 m more line inside the grab, within the 7 m allowed for reeving. The drum stands 3.0 m from the lead sheave for a fleet angle of 1.91 degrees [E2]. The 8 mm line keeps 10.8 kN through its splice: a factor of 10.4 on the working pull and 5.1 on the crank pin's highest release [E3]. The sheaves, the upper sheave included, are 16.2 rope diameters at the pitch line and the drum 22.0 [E4].

## F. Brake and pawl

The band wraps 270 degrees, so the tight side carries 5.20 times the slack side. A 6 kg weight on a 10.2:1 lever gives 598 N on the slack side and 314 N m of holding torque [F1]. The most the line can put on the drum is 186 N m, at the crank pin's limit on the innermost layer: a factor of 1.69, and 2.9 at the working pull [F2]. The ratchet tooth carries 2,211 N at the limit, 17 MPa on its face [F3].

## G. Tripod, cradle, drawbar and capstan stability (R7)

At the limit the lead sheave is pulled 833 N outward and 1,678 N up, and the drawbar pushes the cradle 2,107 N inward. The foot therefore sees the rope along leg A, which is the load case HatchSide was designed for with its own winch [G1]. The 2,470 mm drawbar has an Euler load of 39.4 kN, 19 times the limit [G2]. The capstan weighs 69.7 kg with the long handle; because the rope runs 80 mm above the drawbar, it is pitched forward by 169 N m at the limit, against 253 N m from its weight; the stakes hold it from skating [G3]. The line's rated load is 122 kg, the link's lowest release. Proof at twice the working load is 193 kg, inside HatchSide's 225 kg proof load [G4]. **R7 is met on paper.**

## H. Scraper (R2, R8)

Two toes cutting 150 N each at 615 mm radius need 184 N m, 142 N for each of two people on the T-bar [H1]. The 42.4 x 2.6 mm pole carries that at 30 MPa and winds up 10 degrees over 10 m [H2]. The scraper head weighs 26.1 kg with its arms on, each pole section 7.1 kg and the T-bar 5.6 kg; hung at 10 m it is 67 kg [H3]. At 25 m, with 12 sections, it is 117 kg, 1,262 N with the allowance, under both the crank pin's lowest release on the innermost layer (1,405 N) and the tripod's rating, so 25 m is still the scraper's working limit [H4]. A 10 mm toe blade lapped on each toe plate now reaches 615 mm, 40 mm beyond a 1.0 m ring's outer face (Amish's decision 29B; the first design reached 15 mm); lifted 300 mm on the sleeve the toes fold to 389 mm, inside the 400 mm bore of the smallest ring, with 11 mm to spare [H5]. Against the first design's 590 mm toes the T-bar force rises 4 %; the arms with their blades weigh 5.8 kg [H6]. The fold relies on the sleeve sliding 300 mm down the pole. In the first design a stop collar 40 mm below the sleeve allowed only about 40 mm, so the toes folded only to about 604 mm and the head could not have been lifted out through any ring in the range. Amish's decision 5A (2026-10-04, SKG-DDR-004) replaces the collar with a 340 mm sleeve slotted 13 x 312 mm on each side and a 12 mm cross pin through the pole running in the slots: open, the pin bears on the slot bottoms; lifted, the sleeve slides down until the pin meets the slot tops, a travel of 300 mm, exactly what the fold needs. The sleeve's top stands 15 mm below the hub and the spike stays 110 mm below the foot, so nothing is pushed into the sump floor [H7]. With the whole 25 m string resting on the foot the pin carries 1,262 N in double shear, 6 MPa (a factor of 43), and bears on the pole wall at 20 MPa [H8]. The model checks the folded position: the sleeve slid 300 mm down is held by the pin at its slot tops without touching the pole. **R2 is met by design**, with a longer pair of arms for 1.2 to 1.3 m rings.

## I. Sinking and tilt (R1, R6)

A 1.0 m ring with a 75 mm wall, 0.5 m high, weighs 304 kg. A string of 8 rings with 6 under water weighs 16.4 kN effective, and eight saddles add 1.61 kN, 10 % [I1]. After 3 m of sinking the rings have 10.8 m2 of outer face in the soil, which at 1 to 3 kPa of skin friction holds 10.8 to 32.5 kN [I2]. The string keeps sinking to 3 m only while skin friction stays below 1.66 kPa [I3]. The toe blades cut a 40 mm ring of soil outside the ring's outer face, so the ring slides down through loosened soil rather than soil packed against it; this aims to keep the friction toward the low end of the estimate, but no calculation here can show by how much. **R1 stays at risk:** the outcome depends on a soil property that only the first trial can measure. Removing the soil for 3 m of sinking, out to the toe radius, is about 3.56 m3, 0.28 m3 more than with the first design's toes [I4].

Two dip-tape readings 1,075 mm apart resolve the tilt to ±4.2 mm, 1 in 253; 1 in 80 is 13.4 mm, so the readings can see it clearly [I5]. Whether scraping the high side and moving saddles corrects it is a trial question. **R6 cannot be verified at TRL 3.**

## J. Cycle time and output (R4)

With two people at the cranks a cycle at 10 m takes 22 s to lower, 20 s to take the cranks off and put them back, 10 s to open, 16 s to close, 115 s to hoist and 45 s for the doors and dumping: 3.8 min [J1]. With a third person on the long two-hand handle during the hoist (Amish's decision 27A) the hoist takes 76 s and the cycle 3.17 min, 6 % over the 3 min target [J2]. The output is 402 L an hour of sand in place, so the 3 m of sinking takes about 8.9 h of grabbing [J3]. **R4 is not met on paper, by about 0.2 min:** the hoist is limited by the power the crew can give, not by the gearing, and the 3:1 tackle and its 3.1 kg cost about 4 s a cycle. Amish's decision records that the timed trial settles the remainder.

## K. Masses and cost (R9, R11)

With its arms pinned on, the scraper head weighs 26.1 kg, over the 25 kg limit, so it is carried with its two arms unpinned: 20.1 kg for the head and 6.0 kg for the pair of arms with their pins [K0]. The slotted sleeve and cross pin add 0.9 kg net (the longer sleeve 1.1 kg and the pin 0.06 kg, less the 0.3 kg stop collar), less than the 1.4 kg estimated when the option was posed. The heaviest pieces are then the capstan frame at 22.9 kg, a ballast saddle at 20.6 kg, the scraper head at 20.1 kg, the foot cradle at 19.4 kg and the winding drum at 18.3 kg [K1]. The assembled grab is 51.0 kg, carried by two people; the longest pieces are the pole sections at 2.0 m [K2]. **R9 is met on paper**, with the arms carried separately. Value-engineering target: USD 4,000. Estimated cost of the constructable design: USD 2,566 (USD 1,434 under the target) [K3]. The round-2 changes added USD 55: the upper sheave, cheeks, axle and dead-end arm USD 35, the long handle USD 10 and the toe blades USD 10; the round-3 slotted sleeve and cross pin add USD 5. The kit weighs about 457 kg without ropes, tubs and the tripod [K4].

## M. Results against every requirement

*Table 2. Requirement status from this note [M].*

| ID | Requirement | Value | Target | Status |
| --- | --- | --- | --- | --- |
| R4 | Cycle time at 10 m, three people at the cranks during the hoist | 3.2 min (3.17 min; 3.8 min with two) | 3 min or less | **Not met on paper by about 0.2 min**; the timed trial decides |
| R1 | Water depth reached without de-watering | Sinks while skin friction stays below 1.66 kPa; estimate 1 to 3 kPa; toes cut 40 mm past the ring to keep it low | At least 3 m | **At risk**; friction measured in the first trial |
| R3 | Grab load per bite | 21.2 L at 75 % fill with a 3:1 tackle (50 % more closing force); 14.1 L at 50 % | At least 20 L | Met on paper at the assumed fill; fill confirmed in the test-pit trial |
| R6 | Tilt | Readings resolve 1 in 253; correction by scraping the high side and saddles | 1 in 80 or better | Not verifiable at TRL 3 |
| R5 | Crank force | 54 N each with two people (108 N for one) | 150 N or less | Met on paper |
| R7 | Proof load of lifting parts | Proof 193 kg inside HatchSide's 225 kg; line factor 10.4; link margin 1.15 | 2 times working load | Met on paper |
| R9 | Portability | Heaviest piece 22.9 kg with the scraper arms carried unpinned (scraper head 26.1 kg with them on, 20.1 kg without); kit about 457 kg; longest 2.0 m | 25 kg or less; small pickup | Met on paper |
| R11 | Prototype cost | USD 2,566 | Value-engineering target USD 4,000 | Met on paper, within the target |
| R2 | Fits rings of 0.8 to 1.3 m | Grab 468 mm across; scraper folds to 389 mm radius on a 300 mm sleeve travel (slotted sleeve and cross pin); adjustable toes and skids, longer arms | 0.8 to 1.3 m | Met by design |
| R8 | No person in the well | Every task from the surface; doors cover the shaft | 100 % | Met by design |
| R10 | Local build | Steel section and plate, stick welding, drilling; shell skins rolled | Stick welder and hand tools | Met by design |

Counts: 1 not met (by about 0.2 min), 1 at risk, 1 not verifiable at TRL 3, 5 met on paper, 3 met by design. Amish decided R4, R3 and R1 on 2026-10-03 and the scraper sleeve's travel (R2) on 2026-10-04 (SKG-DEC-001); what is left of R4 and R1 is settled by the timed trial and the first well trial.

## Checks against the TRL 1 concept

| Concept (SKG-PRC-001 v0.1) | This note | Action |
| --- | --- | --- |
| Rope-closed grab with a closing line and a holding line | Two lines need two hoists and two people in step | One line; the head's weight opens the shells (SKG-DDR-001); 3:1 tackle (SKG-DDR-003) |
| Hand capstan on one tripod leg | A 70 kg capstan cannot hang on an aluminium leg | Ground capstan with a drawbar to a cradle under the leg A foot (SKG-DDR-002) |
| HatchSide tripod "can be rated" for the loads | The tripod is rated 150 kg; two people at a crank can reach 8.3 kN | Shear link and crank shear pin (R7) |
| Scraper on a pole or guided frame | A pole is the only way to turn a tool at depth | Centred pole with a centralizer, arms opened by weight |
| Spoil chute and tipping hook | A chute over the mouth must be moved every cycle and cannot cover the shaft | Folding doors and a spoil tub |

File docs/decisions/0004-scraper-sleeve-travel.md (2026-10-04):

---
doc_id: SKG-DDR-004
title: SinkGrab scraper sleeve travel, decision of 2026-10-04 (R2)
project: SinkGrab
doc_type: Design decision record
version: "0.1"
status: Draft
date: '2026-10-04'
author: Amish Chadha
license: CERN-OHL-S-2.0
revisions:
- version: "0.1"
  date: '2026-10-04'
  author: Amish Chadha
  change: "Amish's round-3 decision 5A of 2026-10-04 recorded and carried out in the model, calculations, bill of materials, drawings and build plan"
---

# 0004: Scraper sleeve travel (R2)

- **Date:** 2026-10-04
- **Status:** accepted

## Context

The scraper's two arms are opened by struts from a sliding sleeve: with the foot on the sump floor, the pole's weight slides the pole down through the sleeve and the struts push the arms out. Lifting the pole must let the sleeve slide 300 mm down the pole for the arms to fold to 389 mm radius, inside the 400 mm bore of a 0.8 m ring. While carrying out decision 29B (SKG-DDR-003) the check found that the first design could not do this: a stop collar sat 40 mm below the sleeve and the pole ended 120 mm below it, so the sleeve could slide only about 40 mm, the toes folded only to about 604 mm radius and the head could not have been lifted out through any ring in the range. The build plan's step 14 and joint 10 showed the same fault.

This was posed to Amish as open decision 4 in the design decisions register (SKG-DEC-001) and `docs/REVIEW.md`, and was item 5 of the portfolio's round-3 list. Amish Chadha (owner), 2026-10-04: "For round 3, I agree with all your proposed recommendations".

## Options considered

| Option | What changes | Cost and mass | Effect |
| --- | --- | --- | --- |
| **A (chosen)** | A 340 mm sleeve, its top just below the hub, with a 300 mm slot each side and a 12 mm cross pin through the pole running in the slots; the stop collar goes; the spike stays 110 mm below the foot | About USD 5, 1.4 kg (estimate when posed) | Nothing is pushed into the sump floor; the 330 mm sump limit keeps its meaning; linkage, struts and fold radius unchanged |
| B | Lengthen the bottom pole and spike 320 mm and move the stop collar down | About USD 3, 0.6 kg | The spike end stands about 430 mm below the foot and has to be pushed that far into the sump floor before the arms open |

## Decision

Option A, as recommended. The sleeve is 340 mm of 54 mm tube, from the foot plate to 15 mm below the hub. A slot 13 mm wide and 312 mm long is cut through each side, starting 14 mm above the bottom end and rounded at the top; the strut lugs stay on the other two sides, 100 mm above the bottom, where they were, so the linkage is unchanged. A 12 mm bright steel cross pin, 70 mm long with an R-clip, passes through one slot, a 12.5 mm cross hole in the pole 140 mm above the tip, and the other slot. Open, the pin bears on the slot bottoms; when the pole is lifted the sleeve slides down until the pin meets the slot tops, a travel of 300 mm. The stop collar is removed.

## Consequences

From SKG-CAL-001 v0.3 and `cad/src/model.py` (no overlaps, no parts adrift, and a new fold check: the sleeve slid 300 mm down is held by the pin at its slot tops without touching the pole, and the folded toes are inside the smallest bore):

| Requirement | Before | After | Target | Status |
| --- | --- | --- | --- | --- |
| R2 fit in rings | Folds to 389 mm only on paper; as drawn about 604 mm, so the head jammed under every ring | Sleeve travel 300 mm; folds to 389 mm radius, 11 mm inside a 0.8 m ring's bore | Rings of 0.8 to 1.3 m | Met by design |
| R9 portability | Scraper head 19.2 kg with the arms unpinned (25.2 kg with them on) | 20.1 kg with the arms unpinned (26.1 kg with them on); heaviest piece still the capstan frame, 22.9 kg | 25 kg or less | Met on paper |
| R11 cost | USD 2,561 | USD 2,566 | Value-engineering target USD 4,000 | Met on paper, within the target |

- **Mass.** The longer sleeve adds 1.1 kg and the pin 0.06 kg, and dropping the stop collar saves 0.3 kg: 0.9 kg net, less than the 1.4 kg estimated when the option was posed. The kit is about 457 kg.
- **Strength.** With the whole 25 m string resting on the foot the pin carries 1,262 N in double shear: 6 MPa, a factor of 43, and 20 MPa bearing on the 2.6 mm pole wall. The 12.5 mm hole sits in the bottom pole well below the hub and centralizer, where the pole carries only the T-bar torque.
- **Use.** The spike still stands 110 mm below the foot, so nothing is pushed into the sump floor and the 330 mm sump limit keeps its meaning. When the scraper is lifted, the sleeve and foot hang about 190 mm below the spike; they pass the bore with the folded arms.
- **Cost.** Value-engineering target: USD 4,000. Estimated cost of the constructable design: USD 2,566 (USD 1,434 under the target). The change adds USD 5 to BOM line 15 (230 mm more tube, two slots, the pin and its R-clip, less the collar).
- **Safety.** No change to the safety case. The scraper no longer risks jamming under the ring, so the earlier warning that nobody enters the well to free a jammed head becomes a general rule rather than a likely event. A missing cross pin lets the sleeve drop off the pole on lifting; the pin and R-clip are checked at each pole change.
- **Changed files.** `cad/src/model.py`, STEP and STL, `docs/04-calcs/sizing.py`, `01-sizing.md` (v0.3) and `results.csv`, `bom/bom.csv` (line 15), `docs/03-requirements.md` (v0.5, status only, no requirement restated), `docs/02-concept.md` (v0.5), `docs/05-build-plan.md` (v0.3), `README.md` (cost), SKG-DWG-002 (Rev P4), SKG-DWG-112 and 113 (Rev P2), joints 10 and 14, steps 14 and 15, the overview, concept media and `cad/src/product_model.py`.

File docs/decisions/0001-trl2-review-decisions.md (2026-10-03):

---
doc_id: SKG-DDR-001
title: SinkGrab TRL 2 review decisions
project: SinkGrab
doc_type: Design decision record
version: "0.1"
status: Draft
date: '2026-10-03'
author: Amish Chadha
license: CERN-OHL-S-2.0
revisions:
- version: "0.1"
  date: '2026-10-03'
  author: Amish Chadha
  change: TRL 2 review items decided under Amish's pre-approvals of 2026-10-03
---

# 0001: TRL 2 review decisions

- **Date:** 2026-10-03
- **Status:** accepted

## Context

The TRL 2 review (`docs/REVIEW.md`, TRL 2 section) raised the items below, including the five open questions of SKG-PRB-001 v0.1. On 2026-10-03 Amish wrote: "start with the first 14 repos from the list of 29 projects. I pre-approve the batch runs along with any recommendations you come up with. I also accept any cost overruns or variations from the assumed scope cost." He then wrote, the same day: "Proceed with the remaining 15 scaffolds", under the same pre-approval; SinkGrab is one of those fifteen. Every design recommendation below is therefore decided as recommended. Choices that touch safety take the conservative option, with the evidence that would relax them stated. Partners and regions are the first candidates to approach, not agreements. Requirements that are not met or at risk are not decided here; they are posed to Amish in SKG-DEC-001.

## Options considered

Table 1 lists the options for each item and the one chosen.

## Decision

*Table 1. Items decided on 2026-10-03 under Amish's pre-approvals.*

| # | Item | Options | Decision | What would relax a safety choice |
| --- | --- | --- | --- | --- |
| 1 | Grab type | (a) two-shell clamshell; (b) multi-tine orange peel | (a): two shells from rolled plate on one pin; an orange peel needs four to six tines, each on its own pin and link | Not a safety choice |
| 2 | Grab operation | (a) closing line plus holding line on two hoists; (b) one closing line, grab lowered closed and opened by its head's weight when the line is slacked | (b): one capstan, one rope, two people | Not a safety choice |
| 3 | Overload | (a) size everything on what two people can heave (8.3 kN); (b) a calibrated shear link at the grab's tackle (1.20 to 1.47 kN) plus a 3 mm shear pin in the crank hub that caps the line below the tripod's proof load | (b), conservative: the HatchSide tripod is never loaded past its 150 kg rating by the grab, nor past its proof load by anything | Break tests on a batch of link pins showing a tighter scatter could raise the rated load toward 150 kg, never past it |
| 4 | Hoist | (a) HatchSide's own hand winch; (b) a SinkGrab hand capstan derived from the SiltHaul block, with a single drum, 4:1 chain, pawl and band brake | (b): two people at 50 W each; the HatchSide winch is removed while SinkGrab works | Not a safety choice |
| 5 | Capstan anchor | (a) ground anchors or a sling to a tree; (b) a drawbar to a cradle under the tripod's leg A foot | (b), conservative: the rope pull closes inside the kit, and the tripod sees only its own winch load case | None proposed |
| 6 | Lowering | (a) crank backward with the pawl lifted; (b) cranks removed, lowering on a band brake that a weighted lever holds on | (b), conservative: no spinning cranks, and the brake sets if the operator lets go | A load brake of the automatic (Weston) type, if one is bought and proof-tested, would allow lowering on the cranks |
| 7 | Scraper guide | (a) rope-hung frame bearing on the wall; (b) centred pole in 2 m sections with a centralizer, arms opened by the pole's weight, turned with a T-bar | (b): a rope cannot turn a tool at depth; the arms fold to pass the bore | Not a safety choice |
| 8 | Sand boiling | (a) bail or pump to lower the water inside; (b) no de-watering; water inside stays level with outside; sump at most 330 mm below the cutting edge | (b), conservative: no upward gradient, no pump in or near the well | Trials showing stable sand with a deeper sump could relax the 330 mm |
| 9 | Tilt limits | Check every 5 cycles or every cycle; act at 1 in 80 or earlier | Read every cycle; correct from 1 in 160; stop undercutting at 1 in 80 until corrected (conservative) | Trial records showing tilt changes slowly could reduce the reading interval |
| 10 | Ballast | (a) a ballast frame on the top ring loaded with plates; (b) U-saddles that straddle the top ring wall, each on its own line, placed by where its line is paid out at the rim | (b): no person needed to place them, and each can be moved to the high side | Not a safety choice |
| 11 | Spoil handling and cover | (a) a chute swung over the mouth with a tipping hook; (b) a well-head frame with two folding doors, the grab dumping into a tub on the closed doors | (b), conservative: the shaft is covered whenever the grab is up; the doors also guide the pole and carry the tilt datum | None proposed |
| 12 | Co-design partner | Kerala, Ethiopian highlands, NGO or water department | First candidate to approach: the Kerala Ground Water Department through a district office, with a well-digging crew it already works with; second, a rural water NGO in the Ethiopian highlands (neither agreed) | |
| 13 | Shared blocks | HatchSide tripod; SiltHaul and SaltDrag hand capstan; CalRig proof loads | HatchSide tripod used unchanged except for a 150 mm sheave grooved for 8 mm rope fitted in its head while SinkGrab works; SinkGrab's capstan is recorded as the single-drum variant of the common capstan block; CalRig is the first candidate rig for proof loads | |
| 14 | Patent screen | Release with or without the targeted search | The targeted search of Chinese open-caisson excavator patents for under-curb scraper claims is run before public release | |
| 15 | Budget | Keep `budget_usd` at 4,000 | Kept; it is a value-engineering target, not a limit | |

## Consequences

- SKG-PRC-001 and SKG-REQ-001 move to v0.2 with these choices; the design for construction (SKG-DDR-002) works from them.
- The open questions of SKG-PRB-001 v0.1 are answered on paper; the questions only trials can answer are listed in SKG-PRB-001 v0.2.
- R1, R3 and R4 are not decided here; they are posed to Amish in SKG-DEC-001 with options and a recommendation.

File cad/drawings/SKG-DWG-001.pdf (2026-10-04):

CONCEPT, NOT FOR FABRICATION | SinkGrab · github.com/BoujeeEnjinia1701/sinkgrab

FRONT VIEW
Scale 1:60; looking at the front (along +Y)

TOP VIEW
Scale 1:60; looking down (along -Z)

RIGHT VIEW
Scale 1:60; looking at the right side (along -X)

1460

6385 2495

ISOMETRIC VIEW
Not to scale; tripod not shown; seen from the front right and above, about 30 deg elevation

MAIN DIMENSIONS AND INTERFACES (MM)
Well axis at x = y = 0; collar top 300 above ground; lining ID 1300 Lead sheave at the HatchSide leg A foot: centre 1760 out, 185 up Drum axis 3,000 beyond the lead sheave, 220 up; fleet 1.9 deg
Drawbar 48.3 x 3.2, pins 2,470 apart, 40 up
Line 8 mm: drum underwound, horizontal at 120, up leg A at 53 deg
Head sheave 150 OD for 8 mm rope in the HatchSide cheeks; line drops on the well axis Well-head frame: 50 x 50 x 5 angle, opening 1360 square, on the collar
Doors 1,364 x 680, hinged at y = +/- 695; 64 mm pole hole when closed
Grab shown closed at the dump position, hinge 1,330 up
Capstan: 4:1 chain, 3 mm shear pin, pawl, weighted band brake; +X handle 240 for two Third-angle; front view from -Y
REV | DESCRIPTION | DATE | BY
P1 | Preliminary GA for TRL 3 (from cad/src/model.py) | 2026-10-03 | AC
P2 | SKG-DDR-002: design for construction | 2026-10-03 | AC
P3 | SKG-DDR-003: 3:1 tackle, long crank handle, toe blades | 2026-10-03 | AC
SINKGRAB | github.com/BoujeeEnjinia1701/sinkgrab

## Rope grab well-deepening kit: well-head layout

DRAWING NO.
SKG-DWG-001

REV
P3

SHEET
1 of 1

SIZE

## ANSI B

SCALE
1:60

UNITS
mm
PROJECTION | DATE
2026-10-03

DRAWN
Amish Chadha

MATERIAL / NOTES
Layout only; parts per SKG-DWG-002 and SKG-DWG-101 to 117. HatchSide tripod not shown. PRELIMINARY, NOT FOR FABRICATION
Licensed CERN-OHL-S-2.0 · Design Molecule Lab · designmolecule.com | Generated from cad/src; do not edit by hand

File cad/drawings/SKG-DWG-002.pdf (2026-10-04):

CONCEPT, NOT FOR FABRICATION | SinkGrab · github.com/BoujeeEnjinia1701/sinkgrab

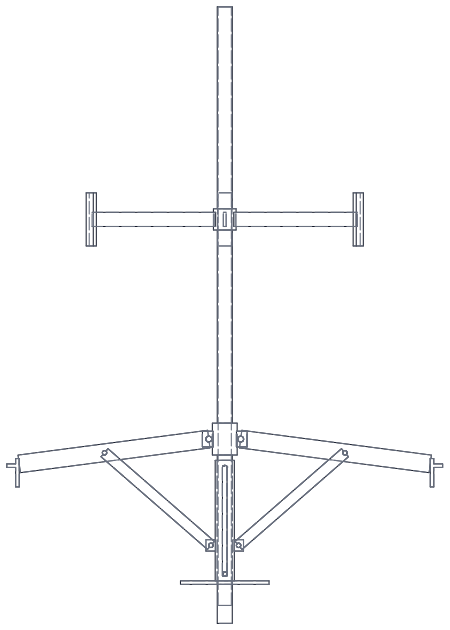
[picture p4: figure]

FRONT VIEW
Scale 1:20; looking at the front (along +Y)

TOP VIEW
Scale 1:20; looking down (along -Z)

RIGHT VIEW
Scale 1:20; looking at the right side (along -X)

2249

677 1834

ISOMETRIC VIEW
Not to scale; grab left (closed), scraper head right (arms open); seen from the front right and above, about 30 deg elevation

MAIN DIMENSIONS AND INTERFACES (MM)
Grab shells R 230 x 340 wide; closed span 468; 28.3 L
Hinge pin 30; tie rods 30 x 10 at 420 centres; head pins at x +/- 120
Head to crosshead stroke 142; open 50 deg, lips 352 apart
Line: guide tube, crosshead sheave, upper sheave, shear link on crosshead (3:1) Shear link pin about 1.9 mm, releases 1.20 to 1.47 kN (break-tested)
Toe blades at 615 radius, 40 beyond a 1.0 m ring's outer face
Arms fold to 389 radius: sleeve slides 300 on a 12 cross pin
Sleeve 54 x 340, slot 13 x 312 each side; no stop collar
Centralizer skids at 440 radius, 700 above the toes
Foot plate 250 dia; sump 330 below the toe line
Pole 42.4 x 2.6 in 2 m sections, 36 spigot and M12 cross bolt Third-angle; front view from -Y
REV | DESCRIPTION | DATE | BY
P1 | Preliminary GA for TRL 3 (from cad/src/model.py) | 2026-10-03 | AC
P2 | SKG-DDR-002: design for construction | 2026-10-03 | AC
P3 | SKG-DDR-003: 3:1 tackle, long crank handle, toe blades | 2026-10-03 | AC
P4 | SKG-DDR-004: slotted scraper sleeve and cross pin | 2026-10-04 | AC
SINKGRAB | github.com/BoujeeEnjinia1701/sinkgrab

## Clamshell grab and under-curb scraper: general arrangement

DRAWING NO.
SKG-DWG-002

REV
P4

SHEET
1 of 1

SIZE

## ANSI B

SCALE
1:20

UNITS
mm
PROJECTION | DATE
2026-10-04

DRAWN
Amish Chadha

MATERIAL / NOTES
Steel plate and section, wear-resistant lips and toes; bought sheave and pins per bom/bom.csv. PRELIMINARY, NOT FOR FABRICATION
Licensed CERN-OHL-S-2.0 · Design Molecule Lab · designmolecule.com | Generated from cad/src; do not edit by hand

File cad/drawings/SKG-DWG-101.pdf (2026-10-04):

### BUILD PLAN SKETCH, PLAN NOT YET BUILT SinkGrab · github.com/BoujeeEnjinia1701/sinkgrab

FRONT VIEW
Scale 1:20; looking at the front (along +Y)

TOP VIEW
Scale 1:20; looking down (along -Z)

RIGHT VIEW
Scale 1:20; looking at the right side (along -X)

537

730 814

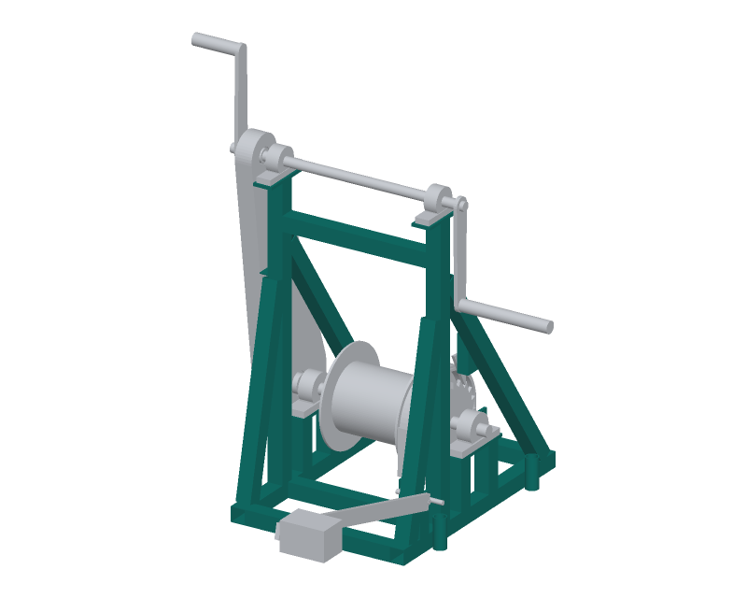
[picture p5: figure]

WHERE IT GOES
This part in colour, its neighbours in grey

HOW TO MAKE IT AND HOW IT FITS
Two side frames 430 apart (bearing planes at -200 and +230 from the drum centre) Each: base rail 660, post 150 behind the drum axis up to the top plate (805 to top) Two pad posts 60 either side of the drum axis; pad 180 x 50 x 8, top at 169
Front brace from the rail front to the post at 640; rear brace to the post at 560 Front and rear cross rails; top tie at 700; brake anchor bar 125 behind the axis Drawbar clevis: two 8 mm plates on the front rail, 21 mm hole 40 up, 32 apart Pawl bracket under the +X front brace, 12 mm pin; brake post and lever plate Four stake tubes 33.7 x 80, 200 either side of the drum axis, outside the rails Tack on a flat table; diagonals within 3 mm; pads level and in line within 1 mm
REV | DESCRIPTION | DATE | BY
P1 | Making sketch for the prototype build plan | 2026-10-03 | AC
SINKGRAB | github.com/BoujeeEnjinia1701/sinkgrab

## Capstan frame: making sketch

DRAWING NO.
SKG-DWG-101

REV
P1

SHEET
1 of 1

SIZE

## ANSI B

SCALE
1:20

UNITS
mm
PROJECTION | DATE
2026-10-03

DRAWN
Amish Chadha

MATERIAL / NOTES
40 x 40 x 2 SHS; 8 mm plate; 33.7 x 3.2 tube; 12 mm bar
Licensed CERN-OHL-S-2.0 · Design Molecule Lab · designmolecule.com | Generated from cad/src; do not edit by hand

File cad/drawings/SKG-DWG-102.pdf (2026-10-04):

### BUILD PLAN SKETCH, PLAN NOT YET BUILT SinkGrab · github.com/BoujeeEnjinia1701/sinkgrab

FRONT VIEW
Scale 1:5; looking at the front (along +Y)

TOP VIEW
Scale 1:5; looking down (along -Z)

RIGHT VIEW
Scale 1:5; looking at the right side (along -X)

549

260 260

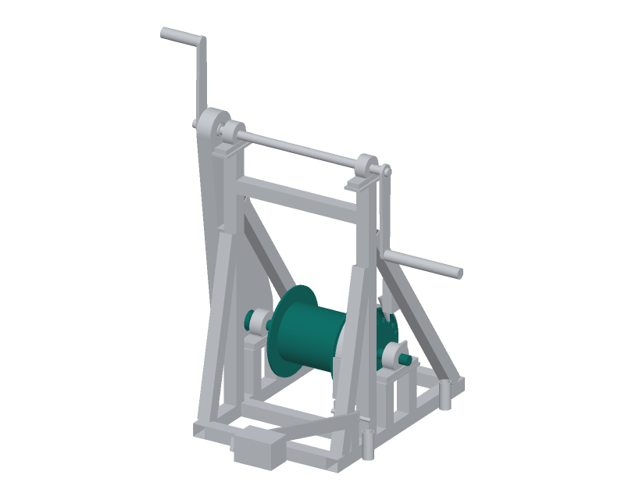
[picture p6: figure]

WHERE IT GOES
This part in colour, its neighbours in grey

HOW TO MAKE IT AND HOW IT FITS
Core 200 long between 6 mm flanges 260 OD (six 36 mm lightening holes)
Holds 23 turns a layer of 8 mm rope; three layers, 41.7 m
Brake drum 250 OD x 50 wide on a 6 mm web, 6 mm outboard of the +X flange Ratchet wheel 20 teeth, 200 OD, 168 root, 8 mm, 8 mm outboard of the brake drum Shaft 30 x 549 through all; weld in short stitches, turning the drum
48-tooth sprocket on a hub at the -X end, outboard of the bearing
Rope clamp with a U-bolt on the -X flange
Check: flanges run true within 1.5 mm; brake drum within 0.5 mm
REV | DESCRIPTION | DATE | BY
P1 | Making sketch for the prototype build plan | 2026-10-03 | AC
SINKGRAB | github.com/BoujeeEnjinia1701/sinkgrab

## Winding drum: making sketch

DRAWING NO.
SKG-DWG-102

REV
P1

SHEET
1 of 1

SIZE

## ANSI B

SCALE
1:5

UNITS
mm
PROJECTION | DATE
2026-10-03

DRAWN
Amish Chadha

MATERIAL / NOTES
168.3 x 4.5 pipe; 6 mm plate; 250 x 6 ring; 8 mm plate; 30 mm S355 shaft
Licensed CERN-OHL-S-2.0 · Design Molecule Lab · designmolecule.com | Generated from cad/src; do not edit by hand

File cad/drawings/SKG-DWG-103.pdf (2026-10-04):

### BUILD PLAN SKETCH, PLAN NOT YET BUILT SinkGrab · github.com/BoujeeEnjinia1701/sinkgrab

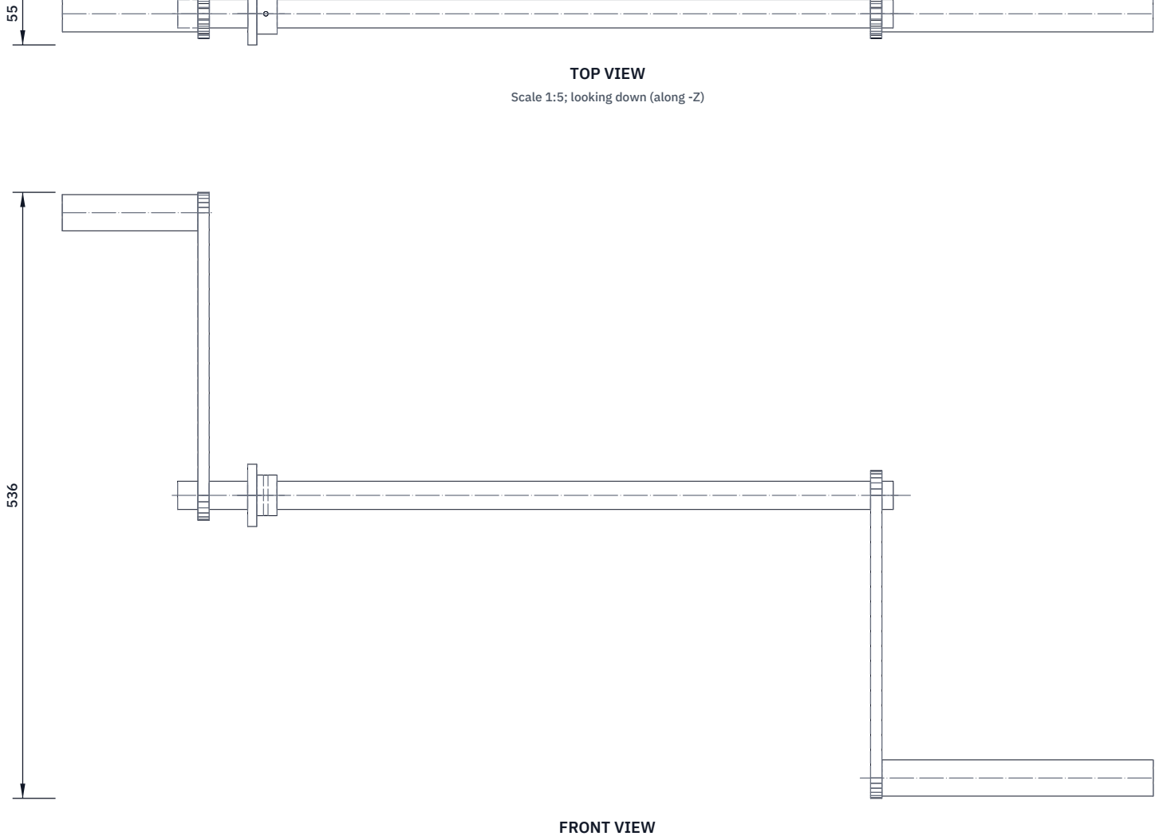
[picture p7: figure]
FRONT VIEW; TOP VIEW; Scale 1:5; looking down (along -Z)

Scale 1:5; looking at the front (along +Y)

RIGHT VIEW
Scale 1:5; looking at the right side (along -X)

965

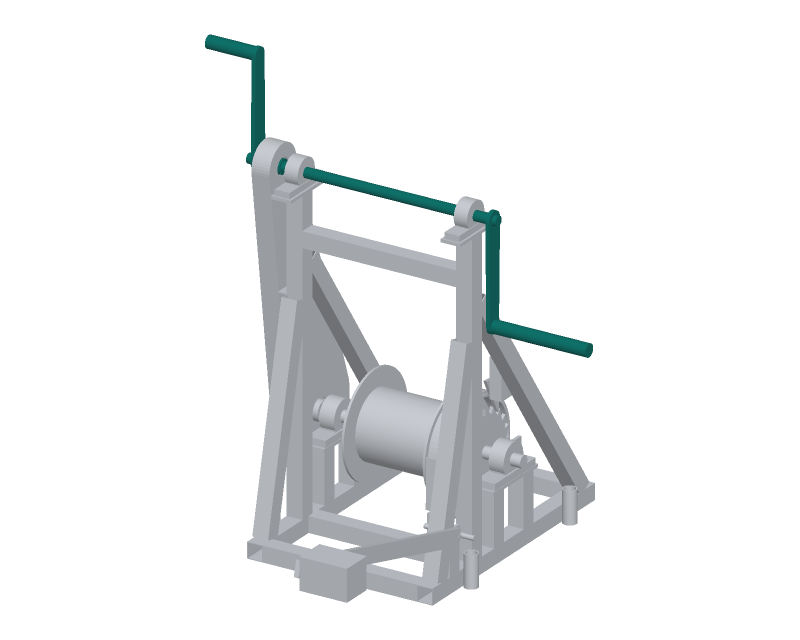
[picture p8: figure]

WHERE IT GOES
This part in colour, its neighbours in grey
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

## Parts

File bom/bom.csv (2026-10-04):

item | qty | spec | supplier | unit_cost_usd | make_buy | notes
1 Capstan frame | 1 | Welded frame: 40 x 40 x 2 mm steel square tube (S235 or S275) about 7.4 m for two base rails, two posts, four pad posts, four braces, two cross rails, the top tie and the brake anchor bar; 8 mm plate for two bearing pads (180 x 50) and two top plates (150 x 50); 8 mm plate for the drawbar clevis (two 70 x 70); pawl bracket from 30 mm plate offcut with a 12 mm pin; brake anchor post and lever plate from 8 mm plate; four stake tubes 33.7 x 3.2 x 80; two 3 mm guard tabs | Local steel stockholder | 70.00 | make | Indicative material price; 22.9 kg from cad/src/model.py; weld with 2.5 mm stick electrodes or MIG (thin wall)
2 Winding drum with brake drum and ratchet wheel | 1 | Core 168.3 x 4.5 mm steel pipe 200 mm long; two 6 mm flanges 260 mm OD with six 36 mm lightening holes; brake drum 250 x 6 mm ring 50 wide on a 6 mm web; spacer ring; 20-tooth ratchet wheel 200 mm OD from 8 mm plate (profile cut); 30 mm bright steel shaft (S355 or EN8) 549 mm long; hub for the big sprocket; rope clamp with U-bolt | Local steel stockholder and profile cutter | 95.00 | make | Indicative price including profile cutting; 18.3 kg with the big sprocket; the big sprocket itself is line 23
3 Pawl | 1 | 8 mm steel plate, profile cut; 12 mm pivot hole; nose radius 3 mm | Profile cutter | 8.00 | make | Indicative price; holds the drum against paying out
4 Crank shaft with shear pin hub and removable cranks | 1 | 25 mm bright steel shaft (S355) 633 mm long with a 3 mm cross hole at the hub; hub from 36 mm tube carrying the 12-tooth sprocket; two crank arms 250 mm between centres from 12 mm plate, each on a 25 mm square-socket boss held by a ball-lock pin; one 32 mm handle tube 120 mm long and one 240 mm long (two hands, for the third person during the hoist) on M12 bolts | Local steel stockholder | 55.00 | make | Indicative price; cranks come off for lowering on the brake; the 240 mm two-hand handle adds about USD 10 (tube, longer bolt, cutting) and about 0.8 kg (Amish's decision 27A, 2026-10-03)
5 Chain guard | 1 | 1.5 mm steel sheet: two side sheets cut round both sprockets with 22 to 30 mm clearance, 46 mm wrap band, holes for both shafts; two M6 screws to the frame tabs | Local fabricator | 20.00 | make | Indicative price; 4.2 kg
6 Band brake with weighted lever | 1 | Band 40 x 3 mm spring steel strip about 1.25 m with bonded brake lining 40 x 5 mm, wrapped 270 deg round the brake drum; anchor end pinned to the anchor post; live end link 25 x 6 flat to a lever of 40 x 12 flat 650 mm long on a 12 mm pivot pin; 6 kg steel block on the lever end; brake on when the lever is let go | Local fabricator and brake lining supplier | 40.00 | make | Indicative price; holding torque about 300 N m (SKG-CAL-001)
7 Ground stakes | 4 | 25 mm round bar 500 mm long, point ground, 34 mm washer head welded on | Local steel stockholder | 4.00 | make | Indicative price; stop the capstan skating; the drawbar is the anchor
8 Foot cradle with sheave cheeks | 1 | 10 mm plate base 320 x 330 under the HatchSide leg A foot with a 120 mm tongue; 4 mm rim on three sides; two clamp bars 260 x 40 x 10 with four M12 bolts over the foot plate; two 8 mm sheave cheeks with 20.5 mm axle holes; two 8 mm drawbar clevis plates with 21 mm holes | Local steel stockholder | 45.00 | make | Indicative price; 19.4 kg; the HatchSide foot is clamped in it
9 Drawbar | 1 | 48.3 x 3.2 mm steel tube in two halves about 1.24 m each joined by a 41 mm spigot 200 mm long; 12 mm tongues with 21 mm holes at both ends; two 20 mm clevis pins with R-clips | Local steel stockholder | 30.00 | make | Indicative price; 11.0 kg; carries the rope pull back to the cradle so the tripod sees only its own winch case
10 Grab head with ballast plates | 1 | Welded box 300 x 120 x 40 from 6 mm plate; two 25 mm head pins 418 mm long through it; 30 mm rope guide tube with 14 mm bore; two 6 mm cheek plates under the box for the upper sheave with 20.5 mm axle holes; 20 mm upper sheave axle with R-clips; recovery-line eye 12 mm plate; two 16 mm ballast plates 190 x 110 bolted on (M10) | Local steel stockholder | 48.00 | make | Indicative price; 13.5 kg with ballast and cheeks; its weight opens the shells when the line is slacked; cheeks and axle for the 3:1 tackle add about USD 3 (plate offcut and bar, Amish's decision 28B, 2026-10-03)
11 Tie rods with pins | 4 | 30 x 10 mm flat 420 mm between hole centres, 20.5 and 25.5 mm holes; 20 mm pins with R-clips at the shell end | Local steel stockholder | 6.00 | make | Indicative price per rod with its pin
12 Grab shells | 2 | Quarter-cylinder scoop 230 mm radius, 340 mm wide (shell B 353 mm): 4 mm skin rolled to radius; two 6 mm end plates with hinge bosses and tie rod lugs; 4 mm top cover; 10 x 50 mm wear-resistant cutting lip (hardox 400 or similar) welded on | Local fabricator with plate rolls | 60.00 | make | Indicative price per shell including rolling; 11.6 and 11.9 kg
13 Crosshead with hinge pin and sheave axle | 1 | Two 10 mm plates profile cut; 10 mm dead-end stub, arm plate and lug (16.5 mm hole) welded to the +Y plate; 30 mm bright steel hinge pin 404 mm long with R-clips; 20 mm sheave axle | Local steel stockholder | 27.00 | make | Indicative price; 3.0 kg; the closing line runs round the crosshead sheave (line 25) and ends at the shear link on the dead-end lug; the dead-end arm adds about USD 2 (10 mm plate offcut, Amish's decision 28B, 2026-10-03)
14 Shear link with calibrated pins | 1 | Two 6 mm plates 87 x 30 on a 16 mm pin through the crosshead dead-end lug; calibrated link pins about 1.9 mm in double shear (mild steel wire from one coil), set by break test to release between 1.20 and 1.47 kN; 20 spare pins | Local fabricator | 15.00 | make | Indicative price; limits the closing line to the tripod's 150 kg rating and opens the grab if it snags
15 Under-curb scraper head | 1 | Bottom pole 42.4 x 2.6 mm tube 1.42 m with a solid spike end and a 12.5 mm cross hole 140 mm above the tip; hub 70 mm OD with two pairs of 8 mm arm lugs; two arms 50 x 10 flat 510 mm long with 10 mm toe plates 100 x 80 and 10 mm toe blades 100 x 35 lapped on them, 25 mm beyond the toe plate (wear-resistant); sliding sleeve 54 mm OD 340 mm long with a 13 x 312 mm slot each side, a 250 mm foot plate and strut lugs; 12 mm cross pin 70 mm long through the pole and slots, with an R-clip; four struts 30 x 6 flat 386 mm; three-arm centralizer with 40 x 150 skids at 440 mm radius (holes for 0.8 to 1.3 m rings); 16 and 12 mm pins | Local fabricator | 75.00 | make | Indicative price; 26.1 kg, carried with the arms unpinned (20.1 and 6.0 kg); arms open under the cutting edge when the pole's weight rests on the foot; the two toe blades cutting 40 mm past the ring add about USD 10 (wear-resistant plate offcut and cutting, Amish's decision 29B, 2026-10-03); the slotted sleeve and cross pin add about USD 5 (230 mm more 54 mm tube, two slots cut, a 12 mm bright bar pin and R-clip; the stop collar is dropped) and 0.9 kg (Amish's decision 5A, 2026-10-04)
16 Pole sections | 6 | 42.4 x 2.6 mm steel tube 2.0 m with a 36 mm spigot 250 mm long welded in (150 mm out); 13 mm cross holes; M12 bolts and nyloc nuts | Local steel stockholder | 18.00 | make | Indicative price each; 7.1 kg each; six reach 12 m (10 m design case); up to 12 for 25 m
17 T-bar with swivel eye | 1 | 48.3 x 2.7 socket 200 mm on the top spigot; 33.7 x 3.2 mm handle 1.4 m; 12 mm eye plate with 18 mm hole for the closing line shackle | Local steel stockholder | 20.00 | make | Indicative price; 5.6 kg
18 Well-head frame | 1 | 50 x 50 x 5 mm angle square frame, 1.36 m opening, in two halves bolted at the corners (M12); four 6 mm datum brackets with 10 mm holes at the caisson wall centre radius; four hinge knuckles 24 mm OD | Local steel stockholder | 70.00 | make | Indicative price; 22.9 kg (two halves of 11.5 kg); sits on the well collar
19 Folding doors | 2 | 40 x 40 x 4 mm angle frame 1.36 x 0.68 m with expanded steel mesh (about 8 kg/m2) welded in; 32 mm pole notch with a 6 mm doubler at the meeting edge; two 16 mm hinge pins each | Local fabricator | 45.00 | make | Indicative price each; 18.3 kg each; cover the well whenever the grab is up and carry the spoil tub
20 Ballast saddles | 8 | U-saddle 200 mm wide from 25 mm plate: inner leg 300 mm, bridge 25 mm, outer leg 20 x 150 mm, 95 mm slot over the ring wall; lifting eye 12 mm plate with 20 mm hole | Local steel stockholder (offcuts) | 30.00 | make | Indicative price each; 20.6 kg each; straddle the top caisson ring wall
21 Drum bearings | 2 | Pillow block ball bearing UCP206, 30 mm bore, cast housing, M14 fixing bolts (in line 34) | Bearing or power transmission distributor | 14.00 | buy | Indicative price; static rating about 11 kN
22 Crank bearings | 2 | Pillow block ball bearing UCP205, 25 mm bore, M12 fixing bolts (in line 34) | Bearing or power transmission distributor | 12.00 | buy | Indicative price
23 Sprockets and chain | 1 | ISO 08B-1 (12.7 mm pitch): 12-tooth sprocket bored to suit the hub, 48-tooth plate wheel bored 30 mm, 1.6 m of chain (breaking load at least 17.8 kN) with one connecting link | Power transmission distributor | 60.00 | buy | Indicative price for the set; 4:1
24 Crank shear pins | 20 | 3 mm S235 bright mild steel bar cut 40 mm long, with split pins; never hardened steel | Local steel stockholder | 0.40 | buy | Indicative price each; releases at about 42 N m on the crank shaft
25 Sheaves | 4 | Steel or nylon sheave 150 mm OD, 130 mm pitch diameter, groove for 8 mm fibre rope, 28 mm wide, 20 mm bore with ball bearing, rated at least 500 kg: one lead sheave, one crosshead sheave, one upper sheave in the grab head (3:1 tackle), one to replace the HatchSide head sheave while SinkGrab works | Rigging or hardware supplier | 30.00 | buy | Indicative price each; the HatchSide sheave is grooved for 6 mm wire; the fourth sheave (upper sheave, about USD 30) is for the 3:1 tackle (Amish's decision 28B, 2026-10-03)
26 Closing line | 1 | 45 m of 8 mm polyester double braid, minimum breaking strength at least 12 kN, eye splice with thimble at the grab end; other end clamped on the drum | Rope or rigging supplier | 60.00 | buy | Indicative price including the splice
27 Recovery line | 1 | 40 m of 8 mm polyester double braid tied to the grab head eye and made off at the well head | Rope or rigging supplier | 35.00 | buy | Indicative price; recovers the grab if the shear link releases
28 Saddle lines | 8 | 32 m of 6 mm polyester braid each, minimum breaking strength at least 5 kN, eye splice at the saddle end | Rope supplier | 12.50 | buy | Indicative price each
29 Swivel and shackles | 1 | Ball-bearing swivel WLL 500 kg with eye and jaw; four bow shackles WLL 500 kg (8 mm pin); one bow shackle WLL 1,000 kg for the T-bar eye | Rigging supplier | 45.00 | buy | Indicative price for the set
30 Dip tape and plumb line | 1 | 30 m steel or fibreglass measuring tape with a 1 kg weighted foot; plumb bob 500 g on 30 m of braided line | Hardware supplier | 60.00 | buy | Indicative price; tilt from four readings each cycle
31 Gas detector | 1 | Four-gas detector (O2, CO, H2S, flammable) with a hand pump and 30 m sampling line, or a lowering cage on a line | Safety equipment supplier | 550.00 | buy | Indicative price; test the shaft air before anyone works at the well head and before any entry
32 Spoil tubs | 2 | Heavy-duty builder's barrow or tub, 90 L, rated at least 150 kg | Hardware supplier | 80.00 | buy | Indicative price each; two bites (about 85 kg) per tub
33 Barrier kit and briefing card | 1 | Four 1.2 m steel stakes, 30 m of barrier rope, two signs, a laminated card with the stop rule and hand signals, two whistles | Hardware supplier | 40.00 | buy | Indicative price; barrier 2 m outside the tripod feet
34 Fasteners and consumables | 1 | M14 x 50 and M12 x 45 bolts for the bearings, M12 clamp bolts, M10 and M6 screws, R-clips, split pins, ball-lock pins, primer and paint, electrodes and discs | Hardware supplier | 60.00 | buy | Indicative price

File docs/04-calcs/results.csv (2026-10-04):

id | requirement | value | target | status
R1 | Water depth reached without de-watering | Sinks while skin friction < 1.66 kPa; estimate 1 to 3 kPa; toes cut 40 mm past the ring to keep it low | At least 3 m | At risk; friction measured in the first trial
R2 | Fits rings of 0.8 to 1.3 m | Grab 468 mm across; scraper folds to 389 mm radius on a 300 mm sleeve travel; toes and skids adjustable | 0.8 to 1.3 m | Met by design
R3 | Grab load per bite | 21.2 L at 75 % fill with a 3:1 tackle (50% more closing force); 14.1 L at 50 % | At least 20 L | Met on paper at the assumed fill; fill confirmed in the test-pit trial
R4 | Cycle time at 10 m, three people at the cranks during the hoist | 3.2 min (3.8 min with two) | 3 min or less | Not met on paper by about 0.2 min; the timed trial decides
R5 | Crank force | 54 N each with two (108 N for one) | 150 N or less | Met on paper
R6 | Tilt | Resolution 1 in 253; corrected by scraping the high side and saddles | 1 in 80 or better | Not verifiable at TRL 3
R7 | Proof load of lifting parts | Proof 193 kg within HatchSide proof 225 kg; line factor 10.4 | 2 x working load | Met on paper
R8 | No person in the well | Every task from the surface; doors close the shaft | 100 % | Met by design
R9 | Portability | Heaviest piece 22.9 kg (capstan frame) | 25 kg or less; small pickup | Met on paper
R10 | Local build | Steel section, plate, stick welding, drilling; rolled shell skins | Stick welder and hand tools | Met by design
R11 | Prototype cost | USD 2,566.00 | Value-engineering target USD 4,000 | Met on paper, within the target

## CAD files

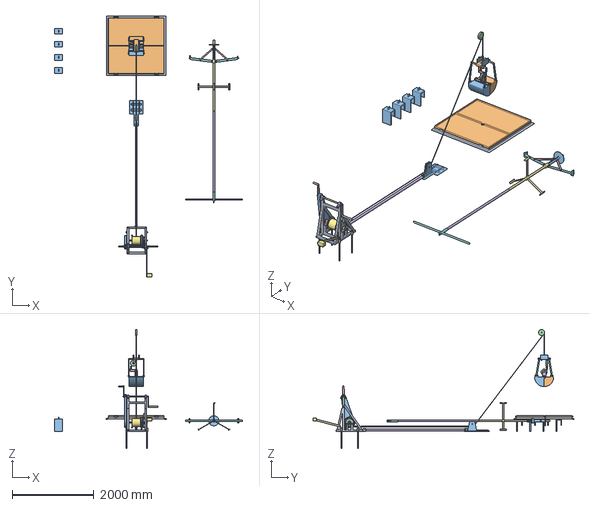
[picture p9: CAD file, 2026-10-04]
cad/step/sinkgrab-assembly.step
4600.0 x 6385.1 x 2915.0 mm

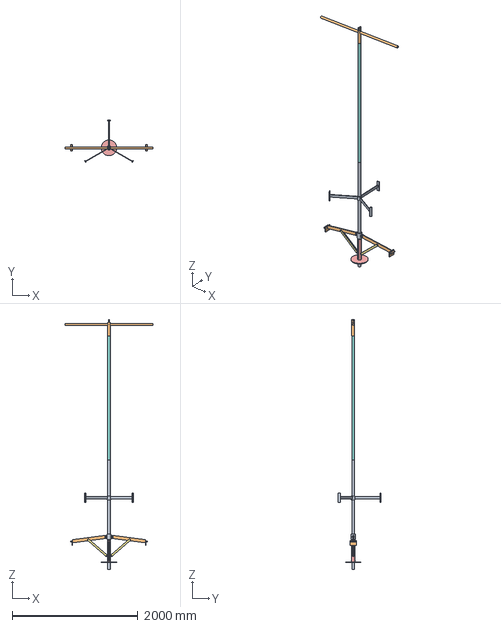
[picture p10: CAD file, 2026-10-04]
cad/step/sinkgrab-scraper.step
1400.0 x 677.3 x 3980.0 mm

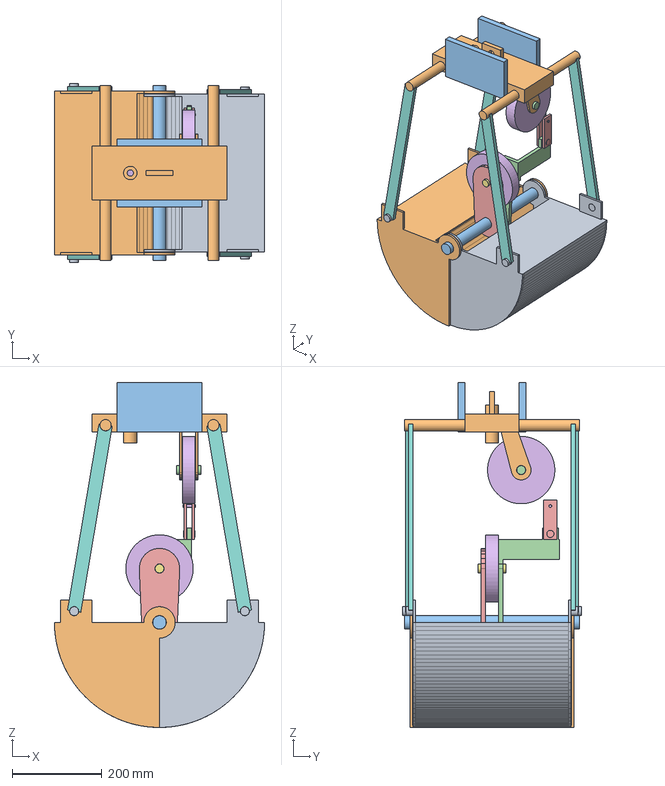
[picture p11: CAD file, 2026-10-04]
cad/step/sinkgrab-grab.step
468.0 x 398.0 x 768.1 mm

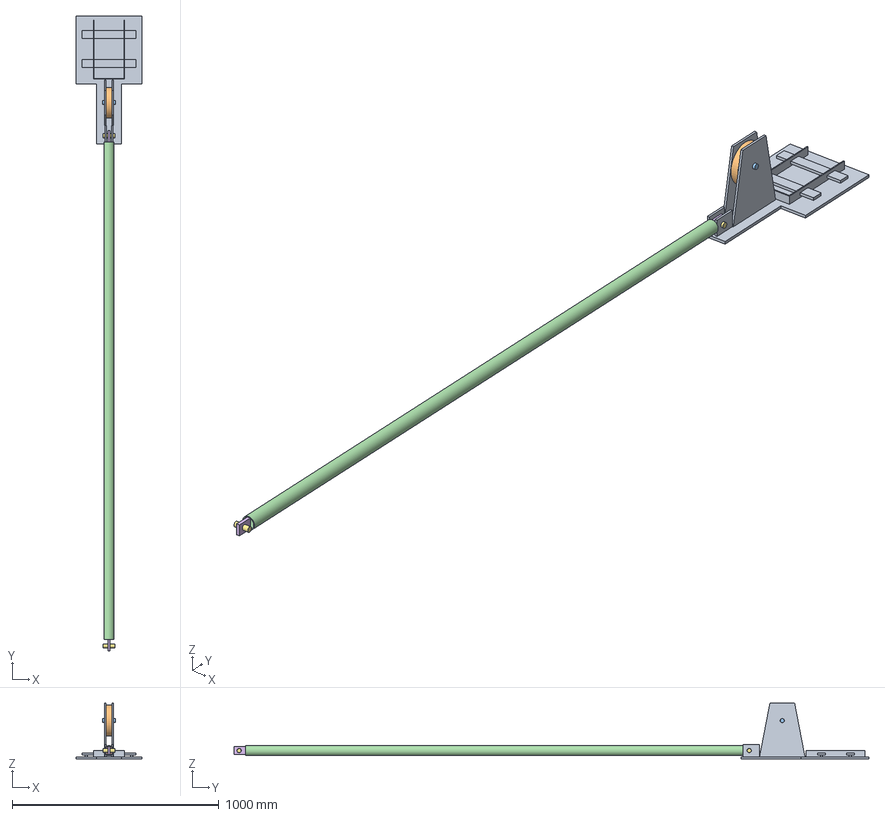
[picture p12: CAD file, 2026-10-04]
cad/step/sinkgrab-lead.step
320.0 x 3075.0 x 270.0 mm

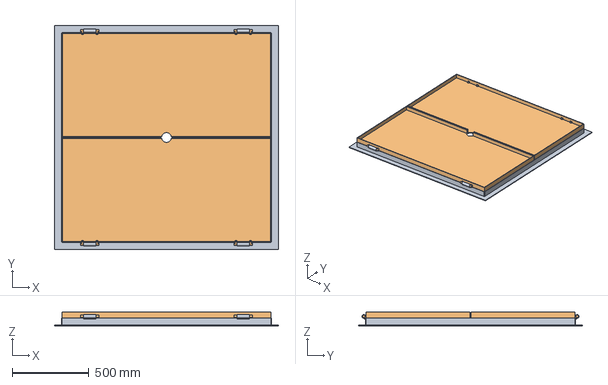
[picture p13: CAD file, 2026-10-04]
cad/step/sinkgrab-wellhead.step
1460.0 x 1460.0 x 90.0 mm

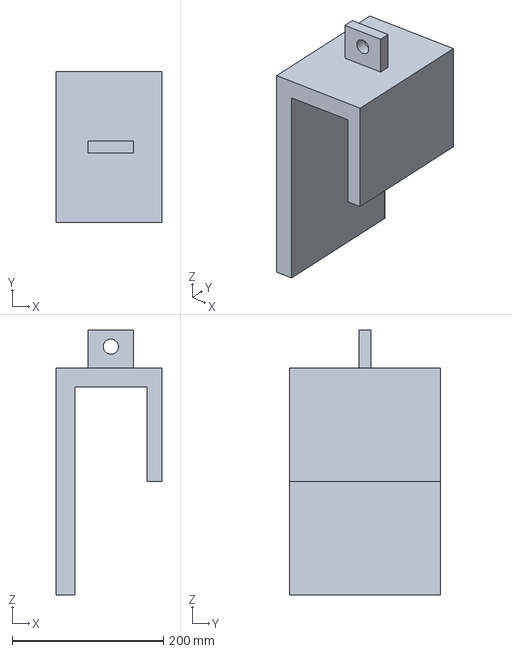
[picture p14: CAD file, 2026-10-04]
cad/step/sinkgrab-saddle.step
140.0 x 200.0 x 350.0 mm

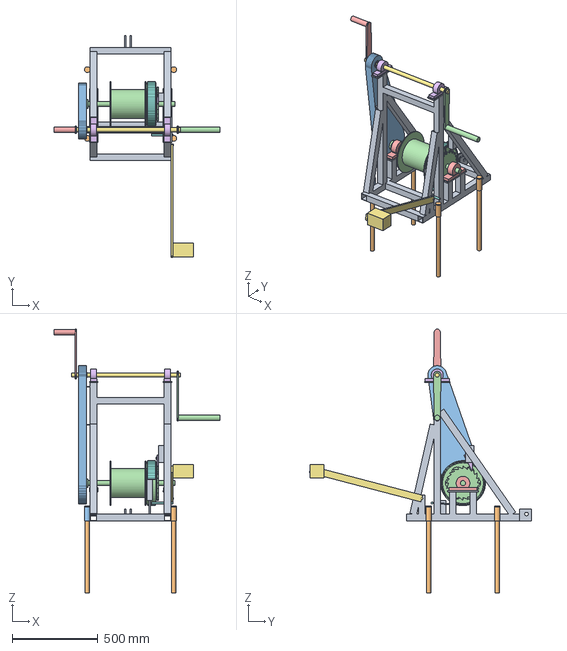
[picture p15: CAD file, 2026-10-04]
cad/step/sinkgrab-capstan.step
965.0 x 1295.1 x 1538.0 mm

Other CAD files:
cad/stl/sinkgrab-capstan.stl
cad/stl/sinkgrab-grab.stl
cad/stl/sinkgrab-lead.stl
cad/stl/sinkgrab-saddle.stl
cad/stl/sinkgrab-scraper.stl
cad/stl/sinkgrab-wellhead.stl

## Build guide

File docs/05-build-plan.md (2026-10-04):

---
doc_id: SKG-BLD-001
title: SinkGrab prototype build plan
project: SinkGrab
doc_type: Build plan
version: "0.3"
status: Draft
date: '2026-10-04'
author: Amish Chadha
license: CERN-OHL-S-2.0
revisions:
- version: "0.1"
  date: '2026-10-03'
  author: Amish Chadha
  change: First build plan; design made constructable (SKG-DDR-002)
- version: "0.2"
  date: '2026-10-03'
  author: Amish Chadha
  change: "Amish's decisions 27A, 28B and 29B of 2026-10-03 (SKG-DDR-003): long two-hand crank handle, 3:1 closing tackle with an upper sheave in the head and the shear link on the crosshead, toe blades 40 mm past the ring; scraper arms carried unpinned"
- version: "0.3"
  date: '2026-10-04'
  author: Amish Chadha
  change: "Amish's decision 5A of 2026-10-04 (SKG-DDR-004): 340 mm slotted sleeve and 12 mm cross pin in place of the stop collar, so the scraper's arms fold to pass the ring; sketches SKG-DWG-112 and 113, joints 10 and 14, step 14 and the overview redrawn"
---

# SinkGrab prototype build plan

**Plan, not yet built.** How to build the first proof-of-concept prototype, component by component. Building and testing to it is TRL 4 work. Decisions are kept in the design decisions register ([docs/06-design-decisions.md](06-design-decisions.md)), not here.

## 1. What you are building

Figure 1. Every component, pulled apart and numbered in build order

*Figure 1. Every component pulled apart and numbered in build order: made parts 1 to 23, bought parts 24 to 26. Ropes, pins and fasteners are not shown.*

The prototype is a kit for deepening a flooded caisson well from the surface. It has five groups: a hand capstan on the ground with a drawbar to a cradle under the HatchSide tripod's leg A foot; a clamshell grab worked on one rope; an under-curb scraper on a pole in 2 m sections; a well-head frame with two folding doors; and eight ballast saddles. You weld the frames, drum, cradle, grab, scraper and saddles from stock steel tube, plate and bar; have the ratchet wheel, pawl and shell end plates profile-cut and the shell skins rolled; and buy the bearings, chain drive, sheaves, ropes, rigging, dip tape, gas detector and tubs. The parts cost about USD 2,566 from the bill of materials. The work needs a stick or MIG welder, a pillar drill, plate rolls (or a fabricator who has them) and hand tools. The HatchSide tripod is built to its own plan.

> **Safety:** SinkGrab is lifting equipment worked over an open well shaft, with a hand-cranked chain drive. A failed pin, rope or shackle can drop the grab; the chain, sprockets, drum, brake and cranks can trap fingers and clothing; the shaft can hold bad air; a person can fall in. The building work involves welding, grinding, rolling plate and lifting parts up to 25 kg. Nobody turns the cranks with the chain guard off, nobody enters the well, and nothing is lifted over the well before the safety stops in section 6 allow it. Load tests are TRL 4 work.

## 2. What changed to make it buildable

The concept showed what SinkGrab does; some of its parts could not be made or fitted as drawn. Each change keeps what SinkGrab does and is recorded in decision record SKG-DDR-002.

*Table 1. Changes from the concept.*

| Component | The concept had | The buildable design has | Why |
| --- | --- | --- | --- |
| Hoist | A capstan clamped on one tripod leg | A ground capstan 3 m from a lead sheave in a cradle under the leg A foot, joined by a drawbar (Figures 15, 13) | The leg cannot carry it; the rope pull stays inside the kit |
| Grab lines | A closing line and a holding line | One line through a 3:1 tackle (over a sheave in the crosshead and one in the head); the head's weight opens the shells (Figures 19, 21) | One hoist, one rope; the 3:1 tackle closes the shells 50 % harder |
| Overload | None | A shear link at the tackle's dead end on the crosshead (Figure 21) and a shear pin in the crank hub (Figure 6) | The tripod is rated 150 kg |
| Lowering | Not defined | Cranks off, lowering on a band brake held on by a weight (Figure 8) | The brake sets if the operator lets go |
| Scraper | A scraper on a pole or a guided frame | Centred pole with a centralizer; two arms opened by struts when the pole's weight rests on the foot (Figures 24, 25) | Turns at depth; folds to pass the bore |
| Spoil chute | A chute and tipping hook | Well-head frame with folding doors; the grab dumps into a tub on the closed doors (Figures 29, 30) | The shaft is covered whenever the grab is up |
| Ballast frame | A frame on the top ring | U-saddles astride the ring wall on their own lines (Figure 32) | Placed and moved from the surface |

## 3. Making the components

Make and check each component before the step that needs it. Sizes are in millimetres. On the capstan, "+X" is the side with the brake and ratchet and "-X" the side with the chain; "front" faces the well. Workshop tolerance is 1 mm unless a step says otherwise. Weld 2 mm tube with MIG or 2.5 mm electrodes; fillets are 3 mm on tube and 5 mm on plate unless stated. Mark every part with its name in paint marker.

### 3.1 Capstan frame

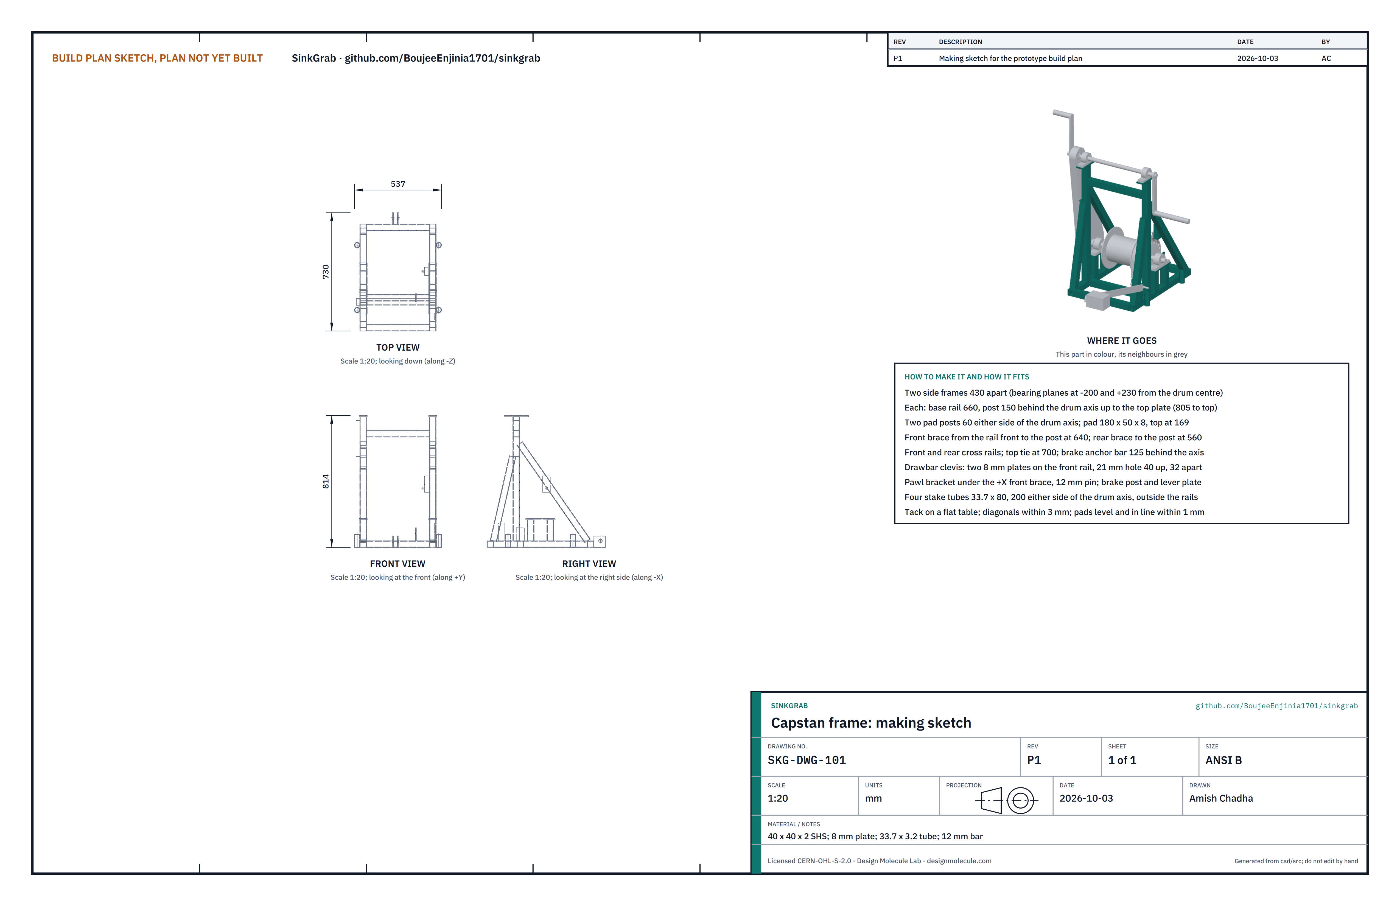
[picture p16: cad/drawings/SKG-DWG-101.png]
Figure 2. Making sketch of the capstan frame


*Figure 2. Capstan frame making sketch (SKG-DWG-101).*

**What it is and what it is made from.** The welded frame that carries the drum, the crank shaft, the pawl and the brake. 40 x 40 x 2 mm steel square tube, about 7.4 m; 8 mm plate; 33.7 x 3.2 mm tube for the stake tubes; 12 mm bar for the pawl pin.

**How to make it.**

1. Cut two base rails 660 long, two posts 765 long, four pad posts 89 long, the cross rails, top tie and brake anchor bar 390 long. Cut the braces to fit in step 4.
2. On each base rail, weld a post upright 150 mm behind the drum axis line and two pad posts 60 mm either side of it.
3. Weld a bearing pad (180 x 50 x 8) on the two pad posts, its top 169 mm above the floor, and a top plate (150 x 50 x 8) on the post, its top 805 mm up.
4. Fit the front brace from the front of the rail to the post near 640 mm up and the rear brace from the rear of the rail to the post near 560 mm up; weld.
5. Stand the two side frames 430 mm apart, centre to centre, on a flat floor. Weld in the front and rear cross rails, the top tie between the posts 700 mm up, and the brake anchor bar 125 mm behind the drum axis.
6. Weld the two drawbar clevis plates (8 mm, 70 x 70, 21 mm hole 40 mm up) to the front cross rail, 32 mm apart and centred.
7. Weld the pawl bracket under the +X front brace with its 12 mm pin pointing inward; the brake anchor post (8 mm plate) on the anchor bar; the lever plate on the outside of the +X rail 240 mm behind the axis.
8. Weld a stake tube (33.7 x 80) upright on the outside of each rail, 200 mm either side of the drum axis, and the two guard tabs on the -X post at 560 and 780 mm up.
9. Drill the pads for two M14 bolts and the top plates for two M12 bolts to the bearings bought.

**How it fits the parts next to it.** The drum bearings bolt on the pads (Figure 4), the crank bearings on the top plates, the pawl hangs on its pin (Figure 7), the brake anchors to the post (Figure 8) and the drawbar pins into the clevis (Figure 15).

**Check before moving on.** Diagonals of the base within 3 mm; both pads level and in line within 1 mm; both top plates likewise; about 23 kg.

### 3.2 Winding drum

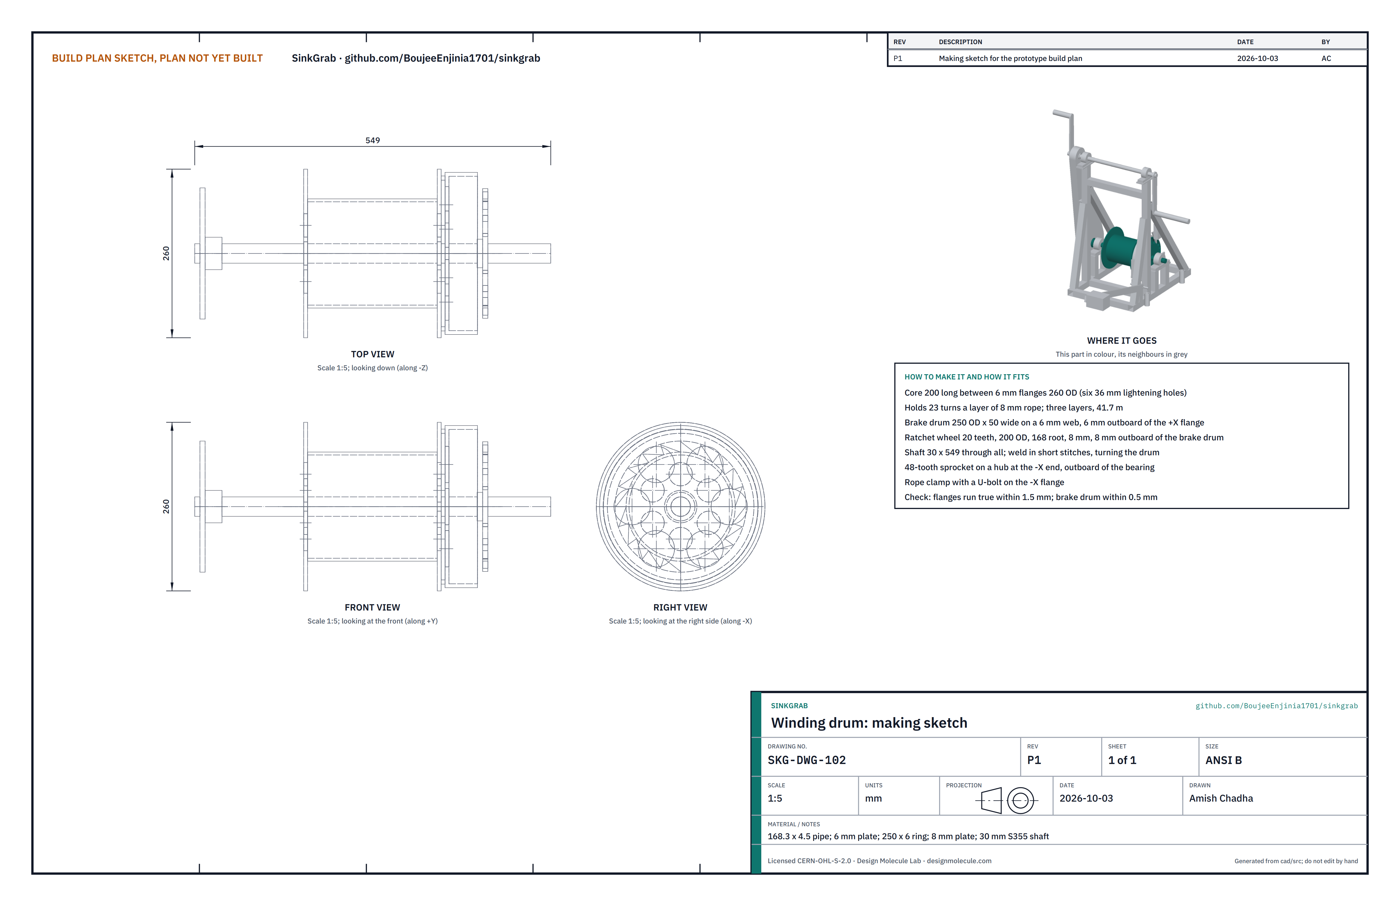
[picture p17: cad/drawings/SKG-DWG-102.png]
Figure 3. Making sketch of the winding drum


*Figure 3. Winding drum making sketch (SKG-DWG-102).*

**What it is and what it is made from.** The drum that winds the line, with its brake drum, ratchet wheel and big sprocket on one shaft. 168.3 x 4.5 mm pipe; 6 mm plate; a 250 x 6 mm ring 50 wide; 8 mm plate for the ratchet; 30 mm bright steel bar (S355 or EN8); the bought 48-tooth sprocket.

**How to make it.**

1. Cut the core 200 mm long with square ends. Cut two flanges 260 mm across from 6 mm plate with a 30 mm centre hole and six 36 mm lightening holes on a 100 mm circle.
2. Push the 549 mm shaft through both flanges; set the flanges on the core ends, the shaft central within 0.5 mm; weld in short stitches, turning as you go.
3. Weld the brake drum web (6 mm, with six 56 mm holes) and ring on the shaft 6 mm outboard of the +X flange, with a spacer ring between.
4. Weld the ratchet wheel (20 teeth, 200 mm outside, 168 mm at the roots) 8 mm outboard of the brake drum, its teeth as in Figure 7.
5. At the -X end, weld the big sprocket on a short hub, outboard of where the bearing will sit.
6. Bolt the rope clamp with its U-bolt to the -X flange.

**How it fits the parts next to it.** The shaft runs in the two drum bearings (Figure 4); the band brake wraps the brake drum (Figure 8); the pawl drops into the ratchet (Figure 7). The line is wound on from below.

**Check before moving on.** Turned in V-blocks, the flanges run true within 1.5 mm and the brake drum within 0.5 mm; about 18 kg.

### 3.3 Drum bearings (bought)

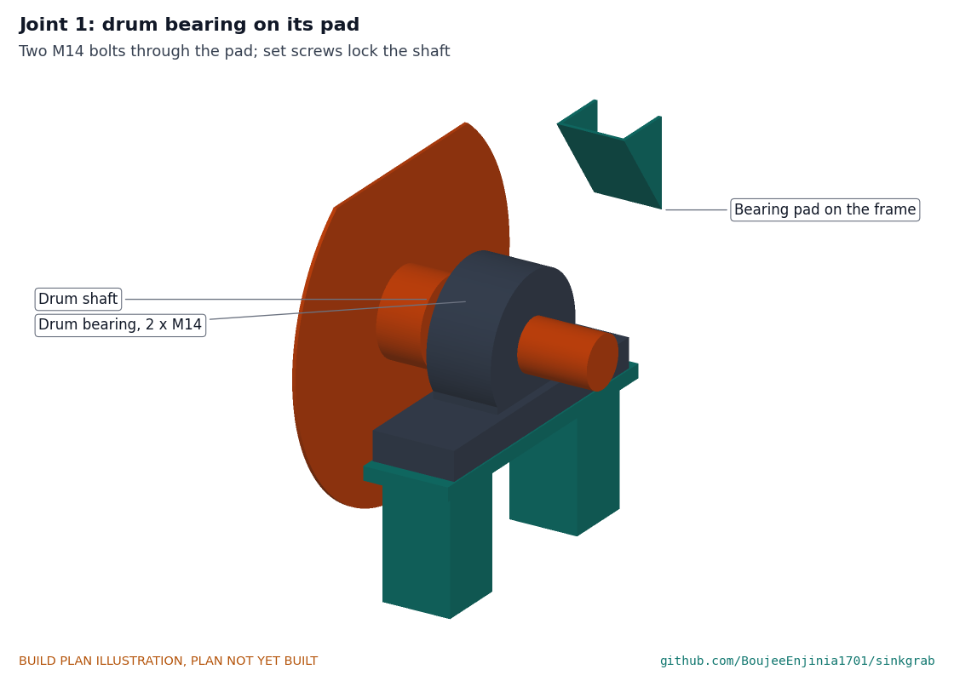
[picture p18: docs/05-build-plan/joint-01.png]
Figure 4. Joint 1: drum bearing on its pad


*Figure 4. Joint 1. Each UCP206 bearing bolts to its pad with two M14 bolts; its set screws lock the shaft.*

Buy two UCP206 pillow block bearings with 30 mm bores. Nothing to make.

### 3.4 Crank shaft, sprocket hub and cranks

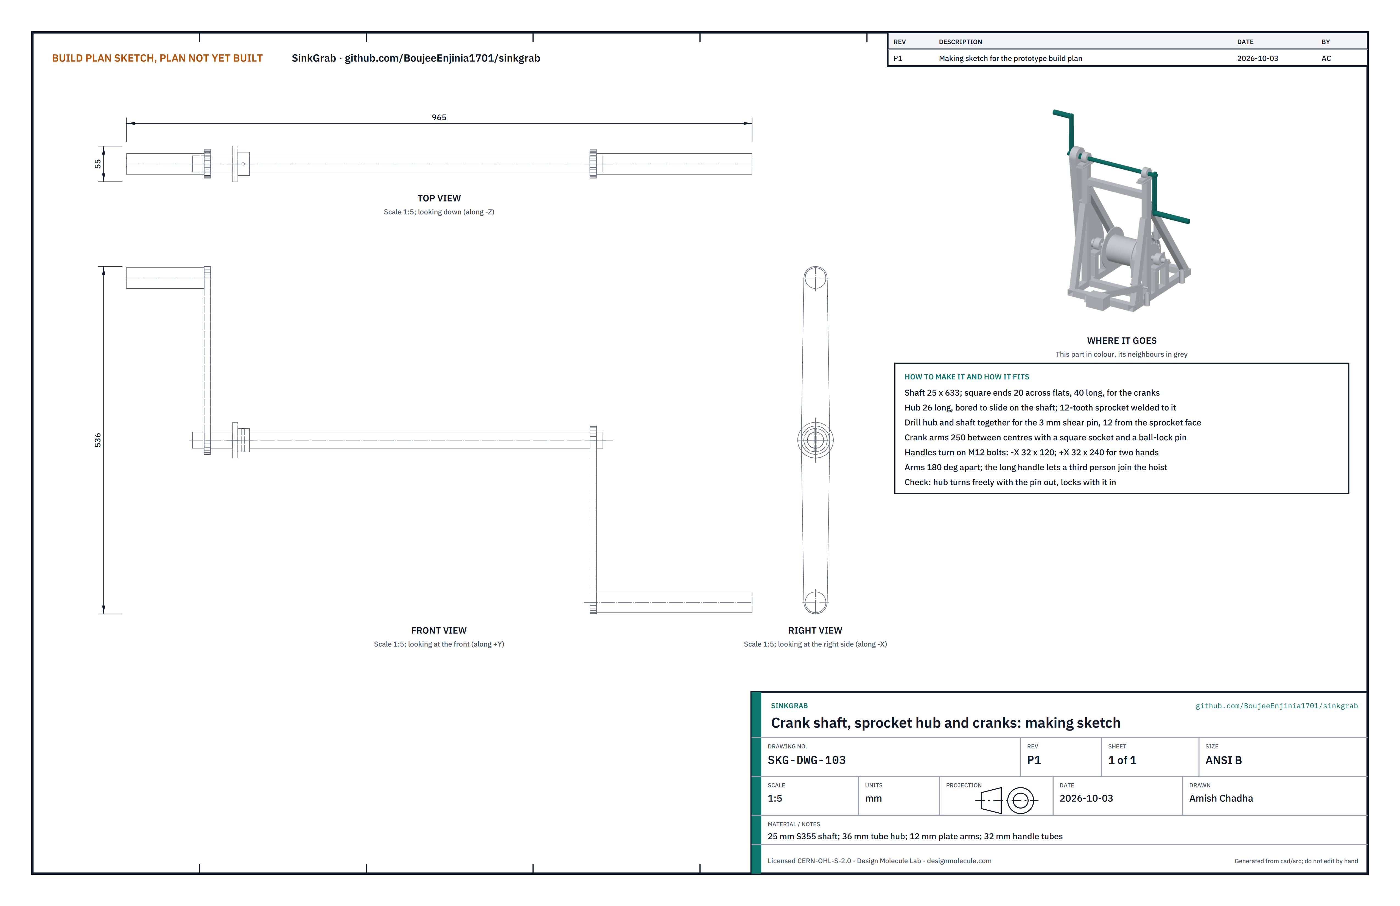
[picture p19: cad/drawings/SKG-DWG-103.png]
Figure 5. Making sketch of the crank shaft, hub and cranks


*Figure 5. Crank shaft, hub and cranks making sketch (SKG-DWG-103).*

**What it is and what it is made from.** The shaft the people turn, and the hub that drives the chain through the shear pin. 25 mm bright steel bar; 36 mm tube for the hub; the bought 12-tooth sprocket; 12 mm plate; 32 mm tube; M12 bolts; two ball-lock pins. One crank has a long handle so a third person can join the hoist.

**How to make it.**

1. Cut the shaft 633 mm long; mill or file a 20 mm square, 40 mm long, on each end for the cranks.
2. Cut the hub 26 mm long from 36 mm tube bored to slide on the shaft; weld the 12-tooth sprocket to it.
3. Slide the hub on the -X end, clamp, and drill a 3 mm hole through hub and shaft together, square to the shaft.
4. Make two crank arms 250 mm between centres, each with a square socket to fit the shaft end and a hole for its ball-lock pin. On the -X crank fit a 32 x 120 handle on an M12 bolt; on the +X crank fit a 32 x 240 handle on a longer M12 bolt, long enough for two people's hands side by side.

**How it fits the parts next to it.**

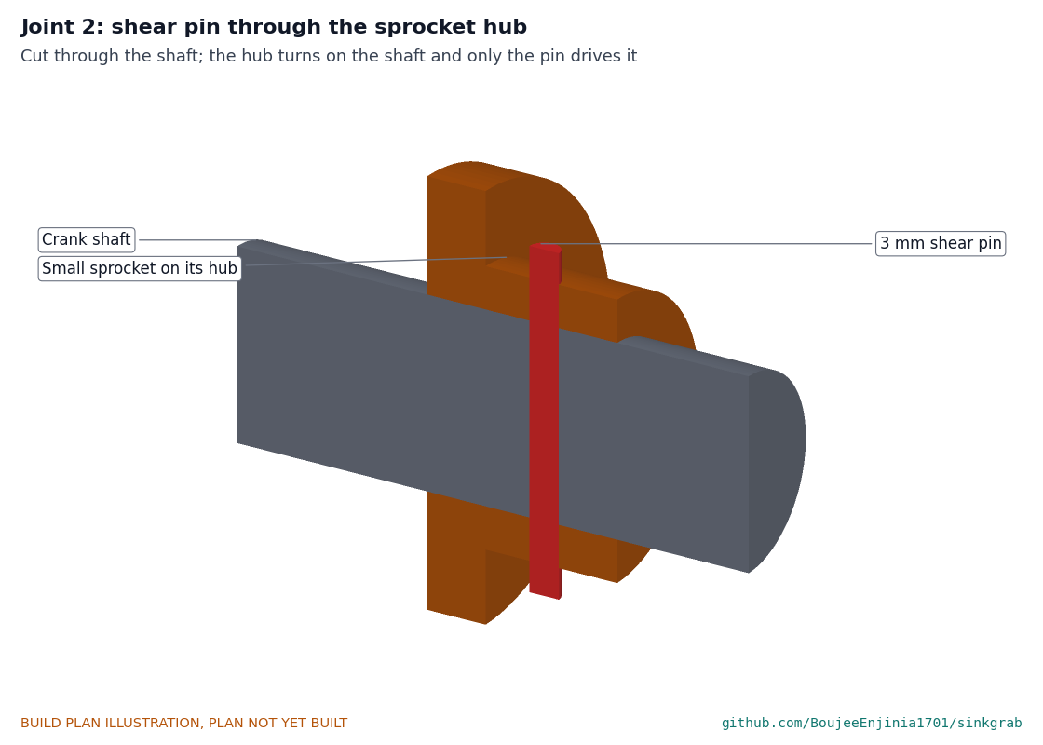
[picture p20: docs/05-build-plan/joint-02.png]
Figure 6. Joint 2: shear pin through the sprocket hub


*Figure 6. Joint 2. The hub turns freely on the shaft; only the 3 mm pin passes the drive. If the line pull passes about 1.5 to 2.1 kN, the pin shears, the cranks spin free and the pawl holds the drum.*

**Check before moving on.** With the pin out the hub turns freely by hand; with it in, it does not move. Each crank slides on and locks with its pin.

### 3.5 Pawl

The pawl is drawn on the brake's making sketch (Figure 9). Cut it from 8 mm plate: a 12 mm pivot hole and a nose with a 3 mm radius that sits 94 mm from the drum axis. Deburr; keep the nose edge square.

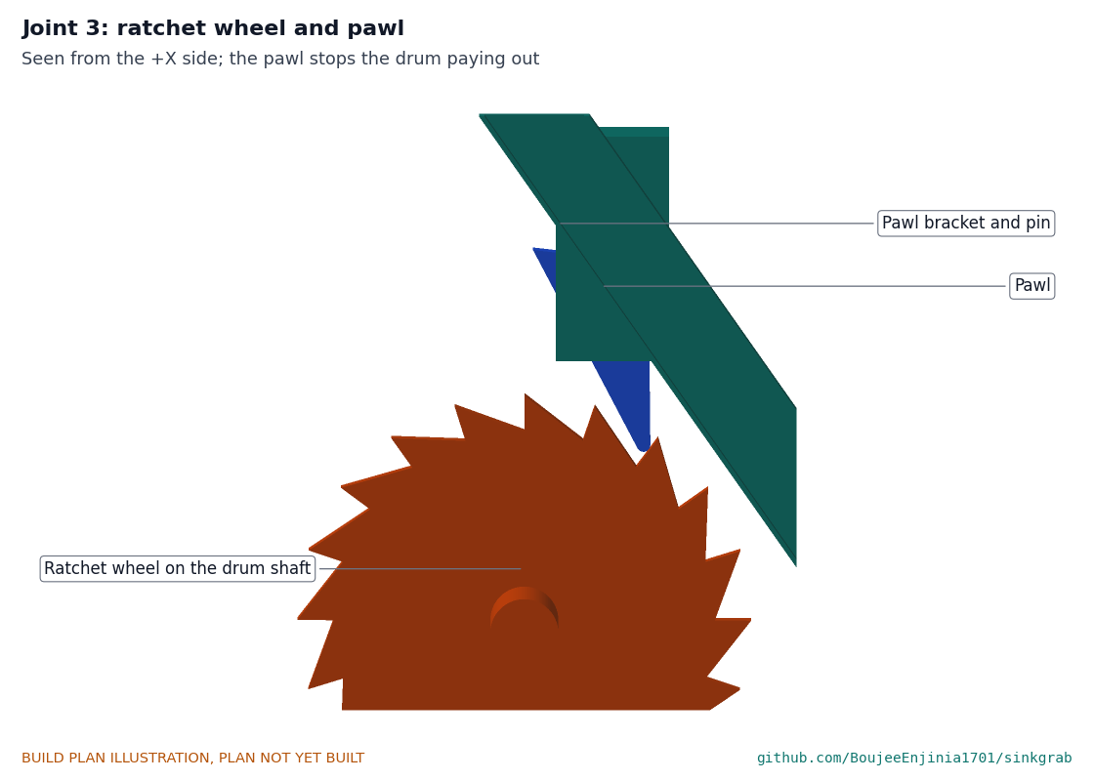
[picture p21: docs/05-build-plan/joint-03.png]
Figure 7. Joint 3: ratchet wheel and pawl


*Figure 7. Joint 3, seen from the +X side. The pawl drops into the ratchet by its own weight and stops the drum turning to pay out line. To lower, it is flipped up onto the bracket.*

**Check before moving on.** The pawl falls into every tooth gap as the drum is turned slowly by hand.

### 3.6 Band brake and weighted lever

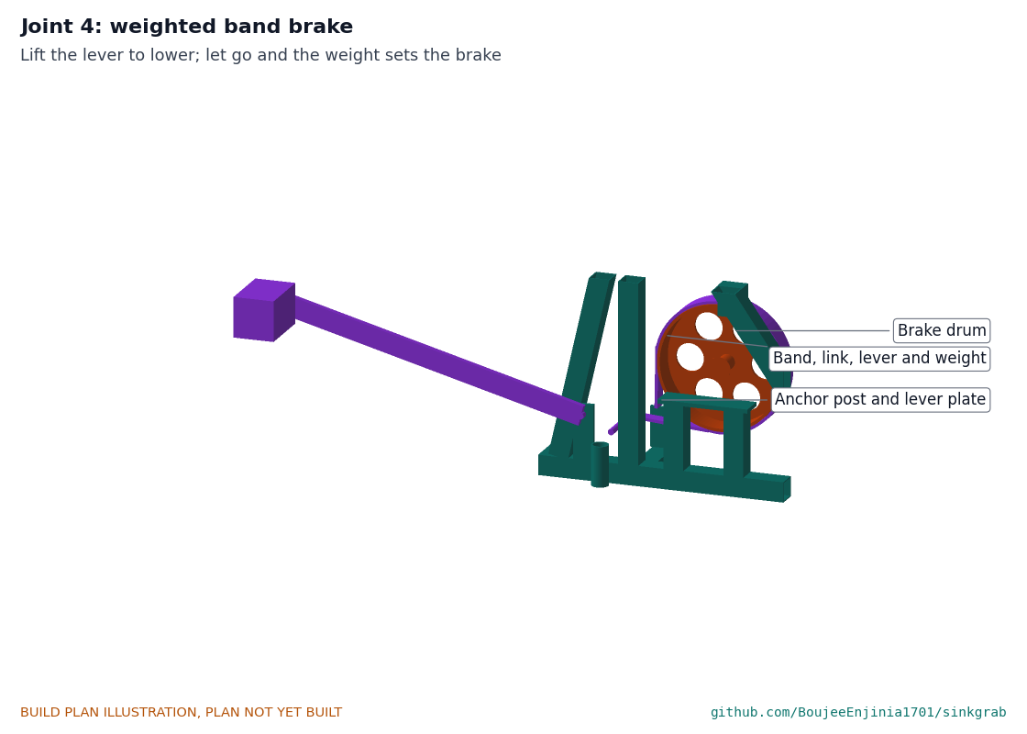
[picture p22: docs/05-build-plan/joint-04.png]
Figure 8. Joint 4: weighted band brake


*Figure 8. Joint 4. The lined band wraps 270 degrees round the brake drum. Its anchor end is pinned to the post; its live end pulls on the lever 60 mm from the pivot. The 6 kg weight at the lever's end holds the brake on; lifting the lever about 30 mm frees the drum.*

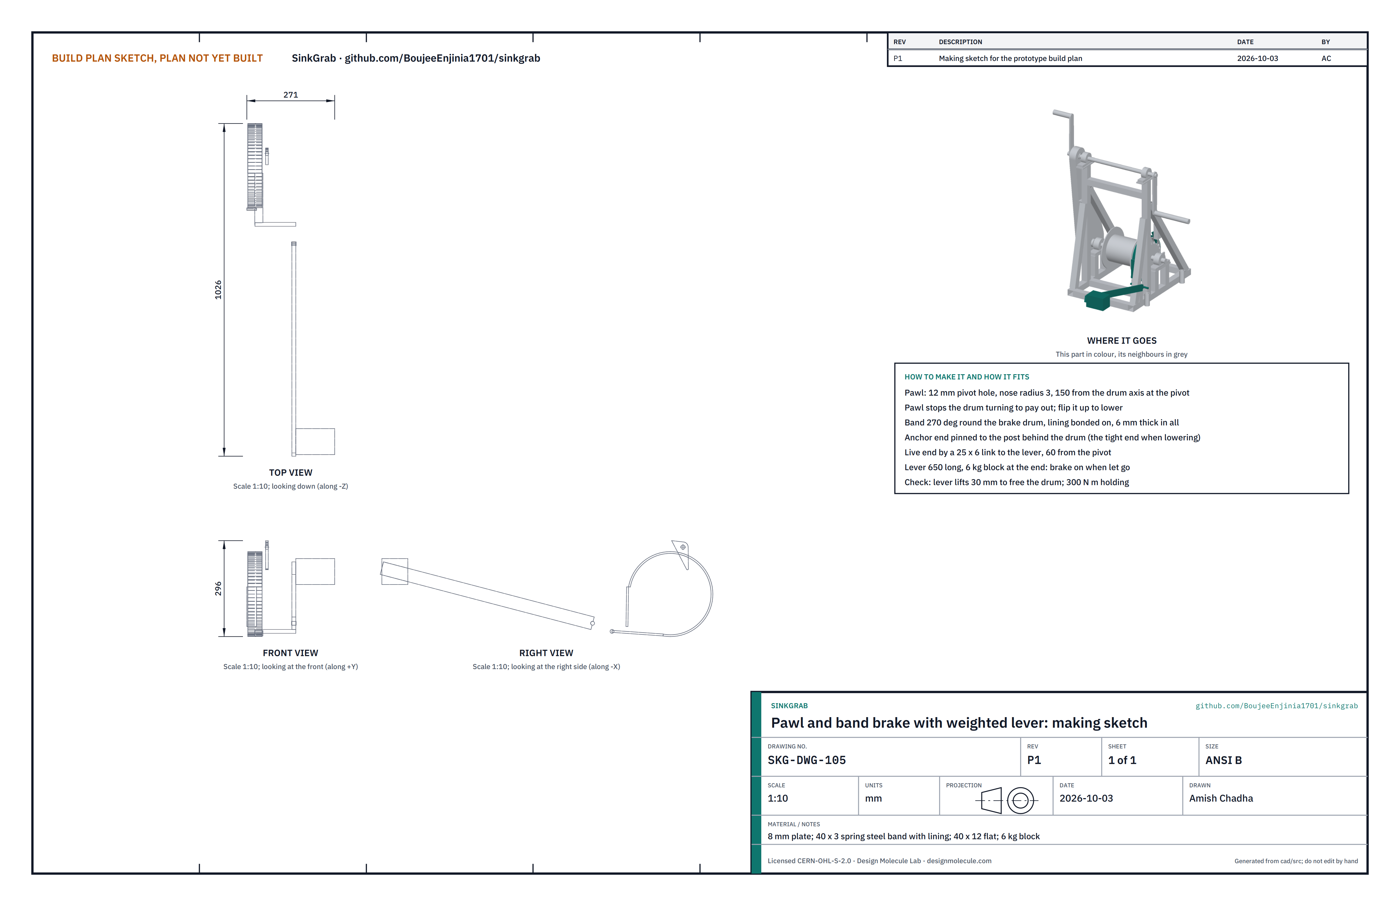
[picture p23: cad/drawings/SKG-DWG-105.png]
Figure 9. Making sketch of the pawl and band brake


*Figure 9. Pawl and band brake with weighted lever making sketch (SKG-DWG-105).*

**What it is and what it is made from.** A brake that is on unless someone holds it off. 40 x 3 mm spring steel strip about 1.25 m with bonded lining; 25 x 6 mm flat for the link; 40 x 12 mm flat 650 mm long for the lever; a 6 kg steel block; 12 mm pins.

**How to make it.**

1. Bond or rivet the lining to the band; form the band round a 250 mm former.
2. Weld an eye at each end of the band; pin the anchor end to the anchor post so the band leaves the drum toward the back.
3. Make the link 25 x 6 with 12.5 mm holes; pin it between the band's live end and the lever, 60 mm from the lever pivot.
4. Pin the lever to the lever plate; weld or bolt the 6 kg block to its far end.

**Check before moving on.** With the weight on, two people cannot turn the drum by the flanges; lifting the lever 30 mm frees it.

### 3.7 Chain guard

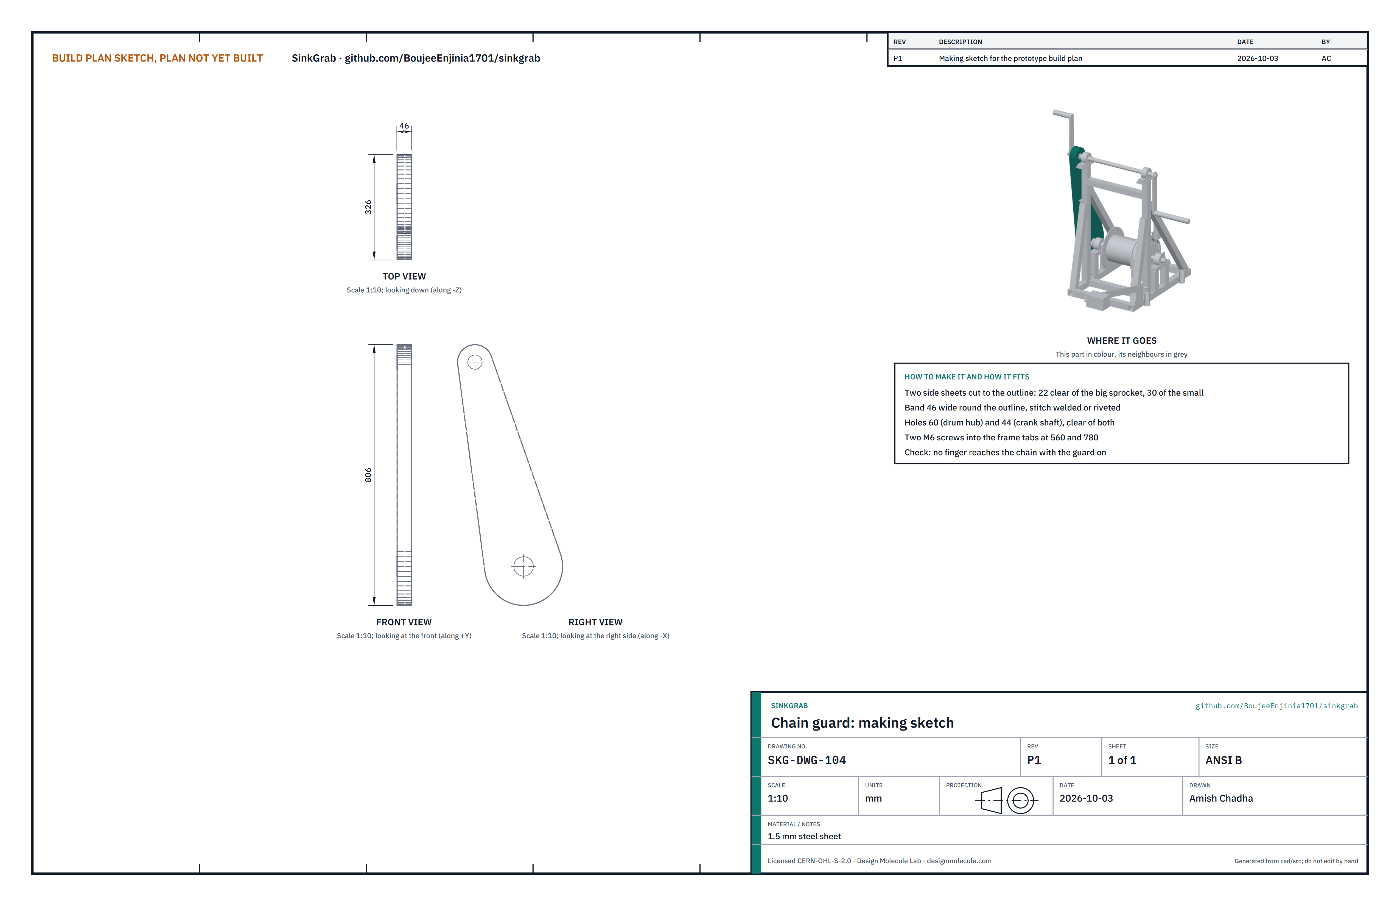
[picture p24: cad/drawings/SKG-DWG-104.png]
Figure 10. Making sketch of the chain guard


*Figure 10. Chain guard making sketch (SKG-DWG-104).*

**What it is and what it is made from.** A closed box round the chain and both sprockets. 1.5 mm steel sheet.

**How to make it.** Cut both side sheets to the outline (22 mm clear of the big sprocket, 30 mm of the small one), cut the shaft holes, bend a 46 mm band round the outline and stitch weld or rivet it to both sheets. Drill for two M6 screws to the frame tabs.

**Check before moving on.** With the guard on, a finger cannot reach the chain or sprockets.

### 3.8 Ground stakes (make 4)

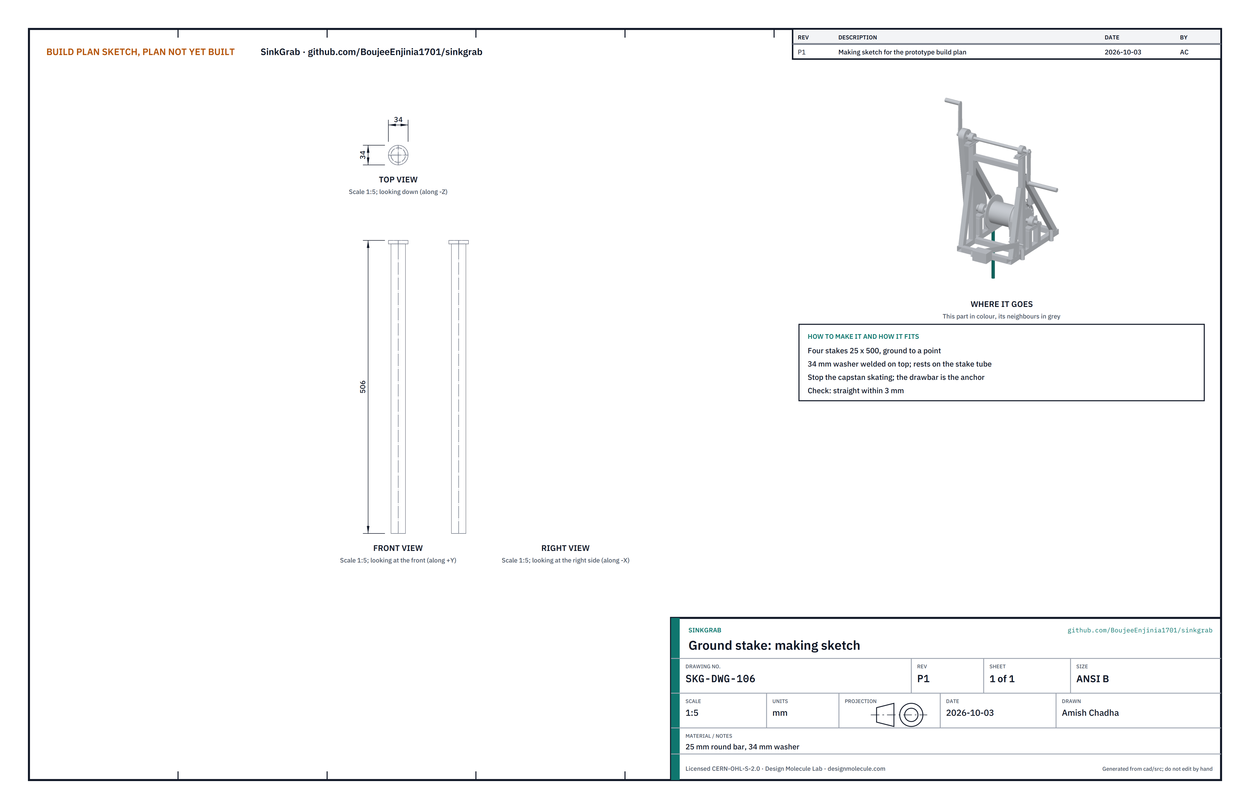
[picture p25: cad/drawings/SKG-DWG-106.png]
Figure 11. Making sketch of a ground stake


*Figure 11. Ground stake making sketch (SKG-DWG-106).*

25 mm round bar 500 mm long, ground to a point, with a 34 mm washer welded on top. Each is driven through a stake tube until its head rests on it. The stakes stop the capstan skating; the drawbar carries the pull. Check: straight within 3 mm.

### 3.9 Foot cradle and lead sheave

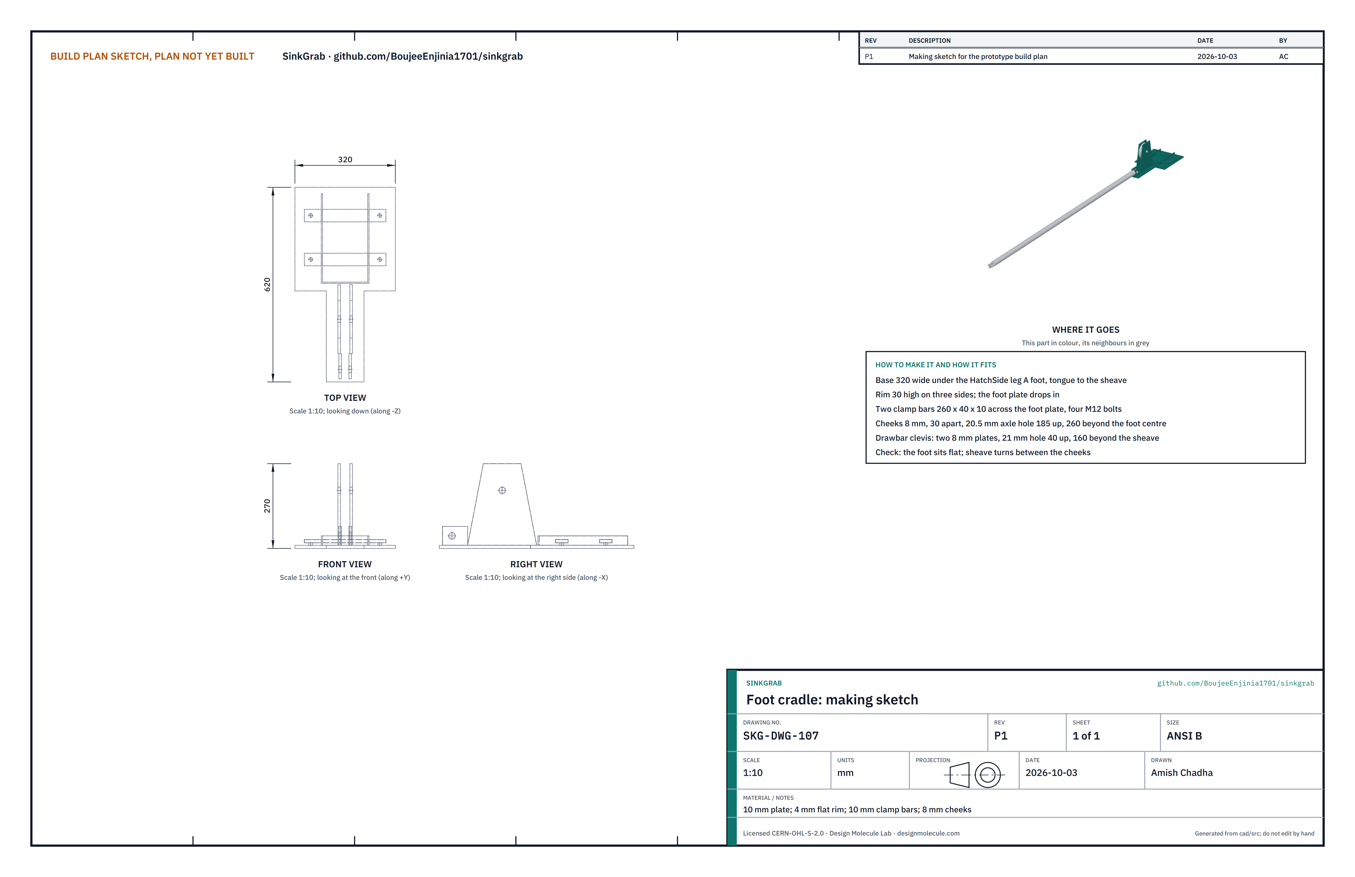
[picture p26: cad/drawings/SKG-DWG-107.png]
Figure 12. Making sketch of the foot cradle


*Figure 12. Foot cradle making sketch (SKG-DWG-107).*

**What it is and what it is made from.** A plate the tripod's leg A foot stands in, carrying the lead sheave and the drawbar clevis. 10 mm plate; 4 mm flat; 10 mm bar for the clamp bars; 8 mm plate; four M12 bolts; the bought sheave on a 20 mm axle.

**How to make it.**

1. Cut the base 320 x 330 with a 120 mm wide tongue running out to the sheave and the clevis.
2. Weld a 30 mm rim of 4 mm flat on three sides of the foot position, open toward the well, 2 mm clear of the foot plate.
3. Drill four 13 mm holes for the clamp bolts, 220 mm apart across and 140 mm apart along.
4. Weld the two sheave cheeks (8 mm, 30 mm apart) on the tongue, their 20.5 mm axle holes 185 mm up and 260 mm beyond the foot centre.
5. Weld the two drawbar clevis plates at the end of the tongue, 21 mm holes 40 mm up, 160 mm beyond the sheave.

**How it fits the parts next to it.**

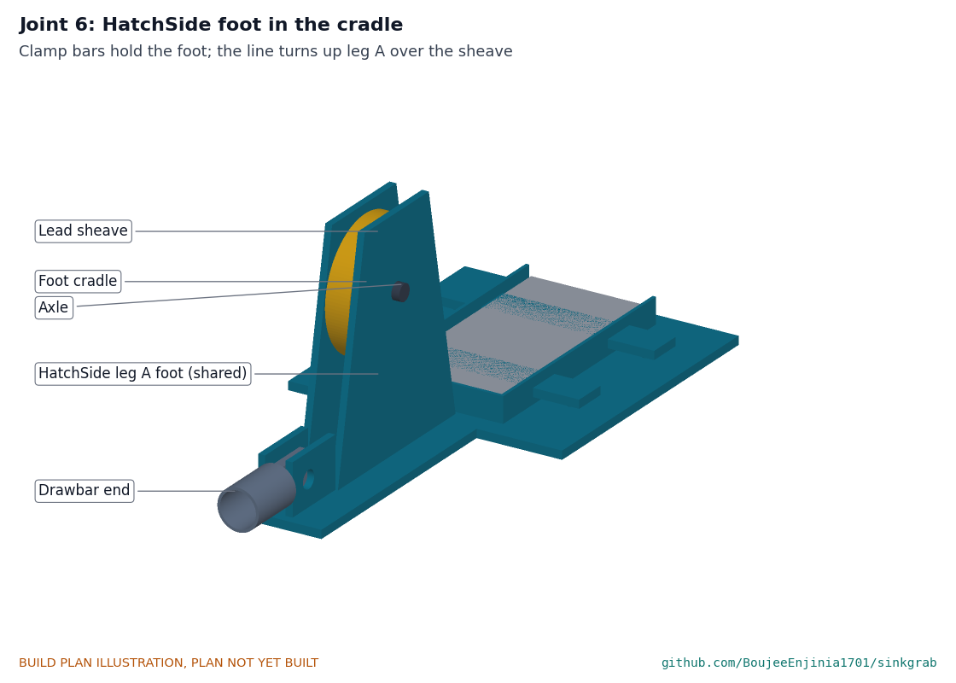
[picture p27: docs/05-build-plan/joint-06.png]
Figure 13. Joint 6: HatchSide foot in the cradle


*Figure 13. Joint 6. The HatchSide foot sits inside the rim; two clamp bars across it pull it down with four M12 bolts. The line comes in under the sheave from the capstan and leaves upward beside leg A.*

**Check before moving on.** The foot drops in and sits flat; the sheave turns freely between the cheeks.

### 3.10 Drawbar

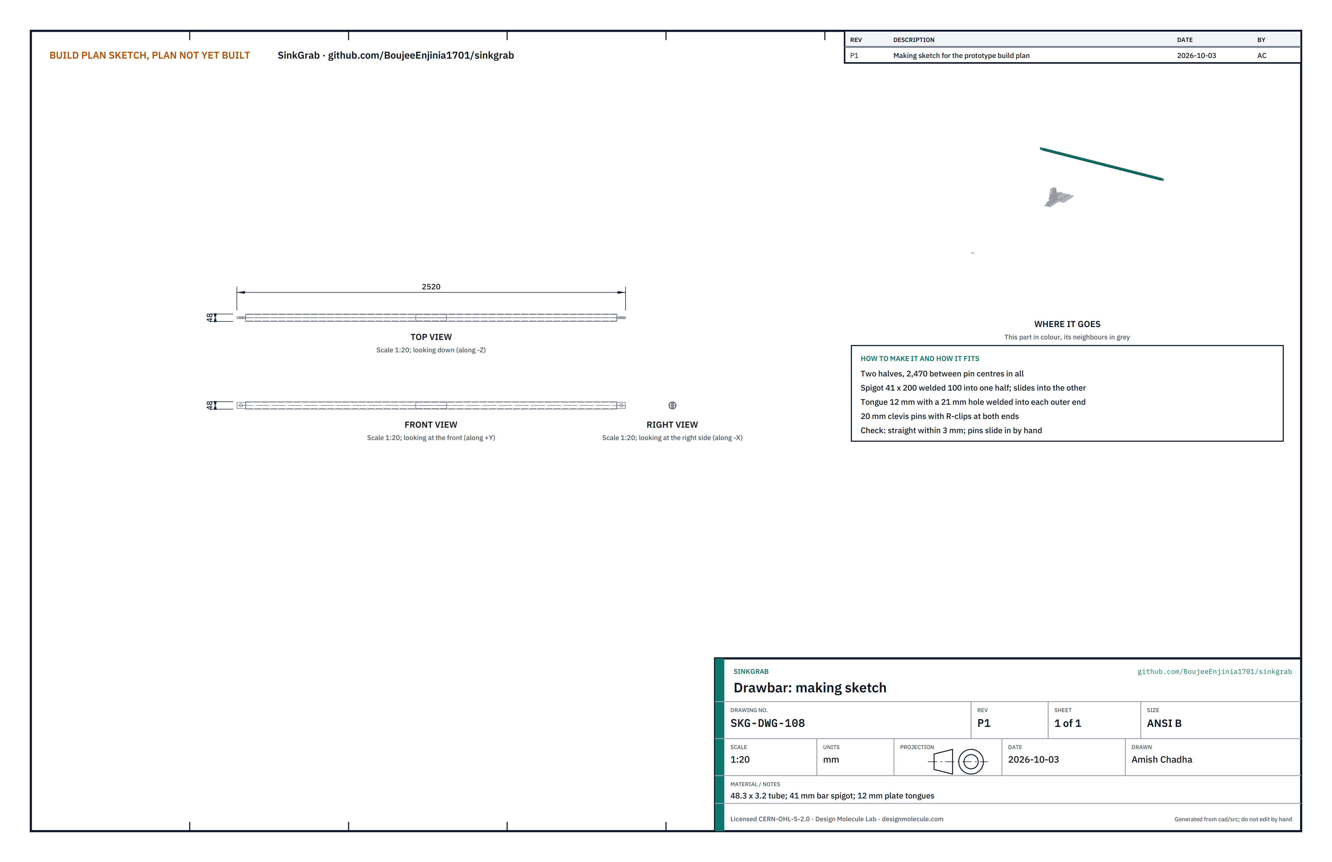
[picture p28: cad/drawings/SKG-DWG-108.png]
Figure 14. Making sketch of the drawbar


*Figure 14. Drawbar making sketch (SKG-DWG-108).*

**What it is and what it is made from.** The strut that carries the line's pull from the capstan back to the cradle. 48.3 x 3.2 mm tube in two halves; a 41 mm bar spigot 200 long; 12 mm plate tongues; two 20 mm clevis pins with R-clips.

**How to make it.** Cut both halves so the pins are 2,470 mm apart when joined. Weld the spigot 100 mm into one half. Slot a 12 mm tongue with a 21 mm hole into each outer end and weld.

**How it fits the parts next to it.**

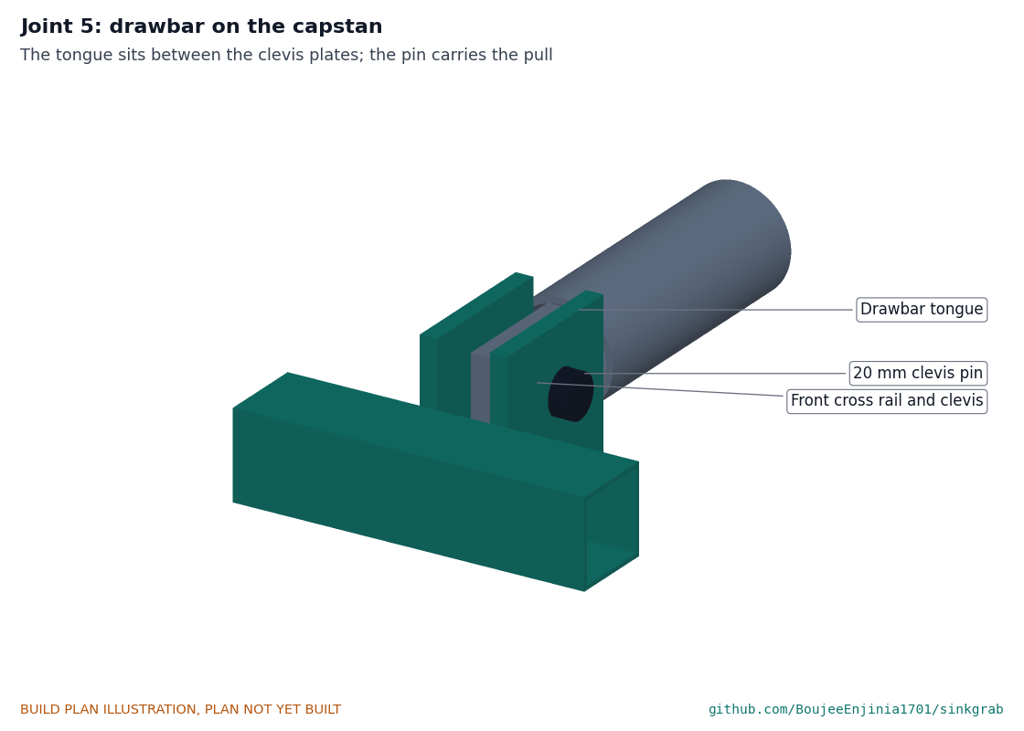
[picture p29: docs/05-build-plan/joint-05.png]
Figure 15. Joint 5: drawbar on the capstan


*Figure 15. Joint 5. The tongue sits between the clevis plates on the capstan's front rail; the 20 mm pin carries the pull. The other end is the same at the cradle.*

**Check before moving on.** Joined, it is straight within 3 mm; both pins slide in by hand.

### 3.11 Grab shells (make 2)

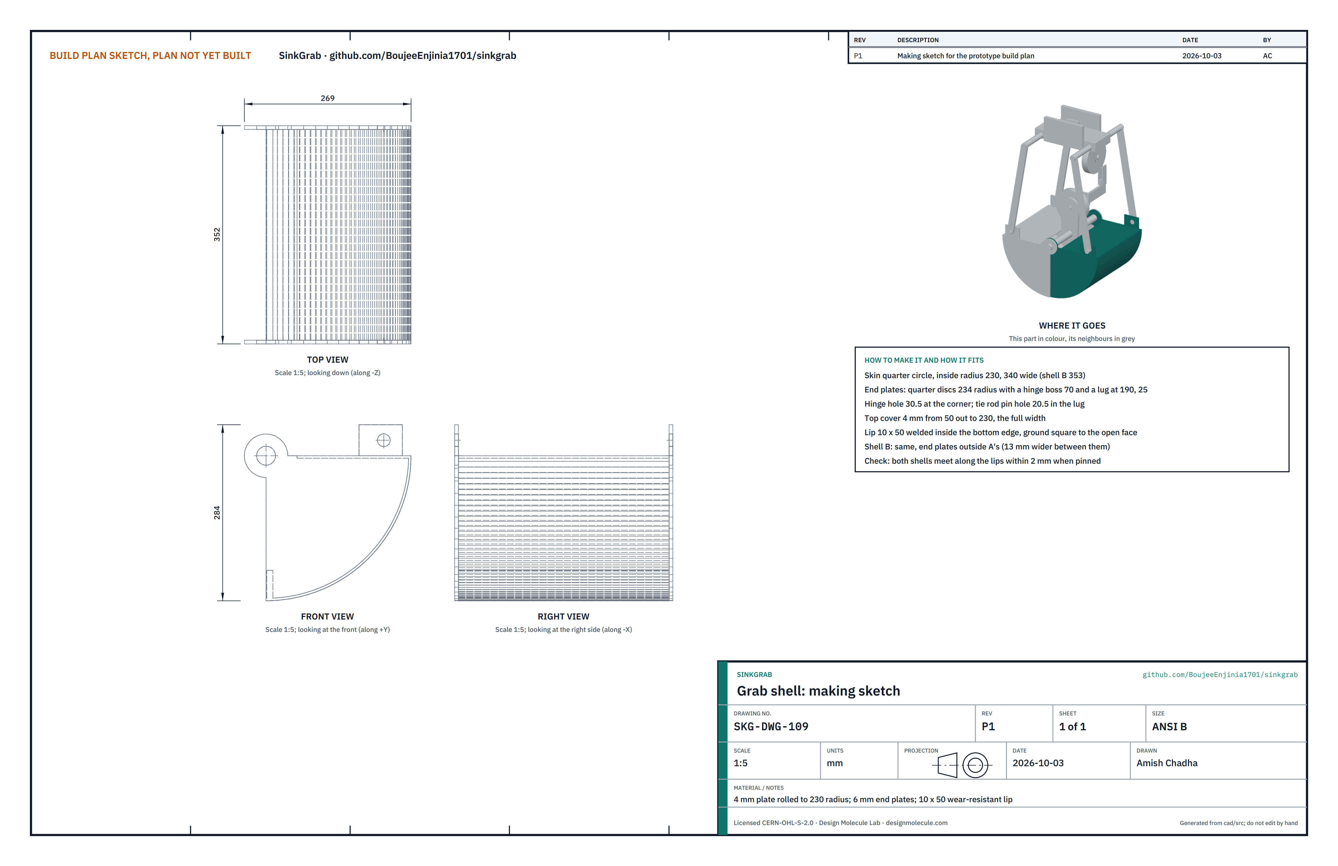
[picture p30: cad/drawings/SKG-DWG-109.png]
Figure 16. Making sketch of a grab shell


*Figure 16. Grab shell making sketch (SKG-DWG-109).*

**What it is and what it is made from.** The two scoops that bite the sand. 4 mm plate rolled to a 230 mm inside radius; 6 mm plate end plates (profile cut); 4 mm top cover; a 10 x 50 mm wear-resistant lip.

**How to make it.**

1. Roll the skin to a quarter circle of 230 mm inside radius, 340 mm wide for shell A and 353 mm for shell B.
2. Profile-cut the four end plates: a quarter disc of 234 mm radius with a 70 mm boss round the hinge corner and a lug at the outer top corner; a 30.5 mm hinge hole and a 20.5 mm tie rod hole.
3. Tack the end plates to the skin, shell B's end plates 13 mm further apart than shell A's so they pass outside A's at the hinge.
4. Weld the 4 mm top cover from 50 mm off the hinge out to the skin.
5. Weld the lip inside the bottom edge and grind its face square to the open side.

**How it fits the parts next to it.** Both shells hang on one 30 mm pin through their end plates and the crosshead (Figure 19); each is closed by two tie rods from its lugs (Figure 20).

**Check before moving on.** Pinned together, the lips meet within 2 mm along their length.

### 3.12 Grab head with ballast plates

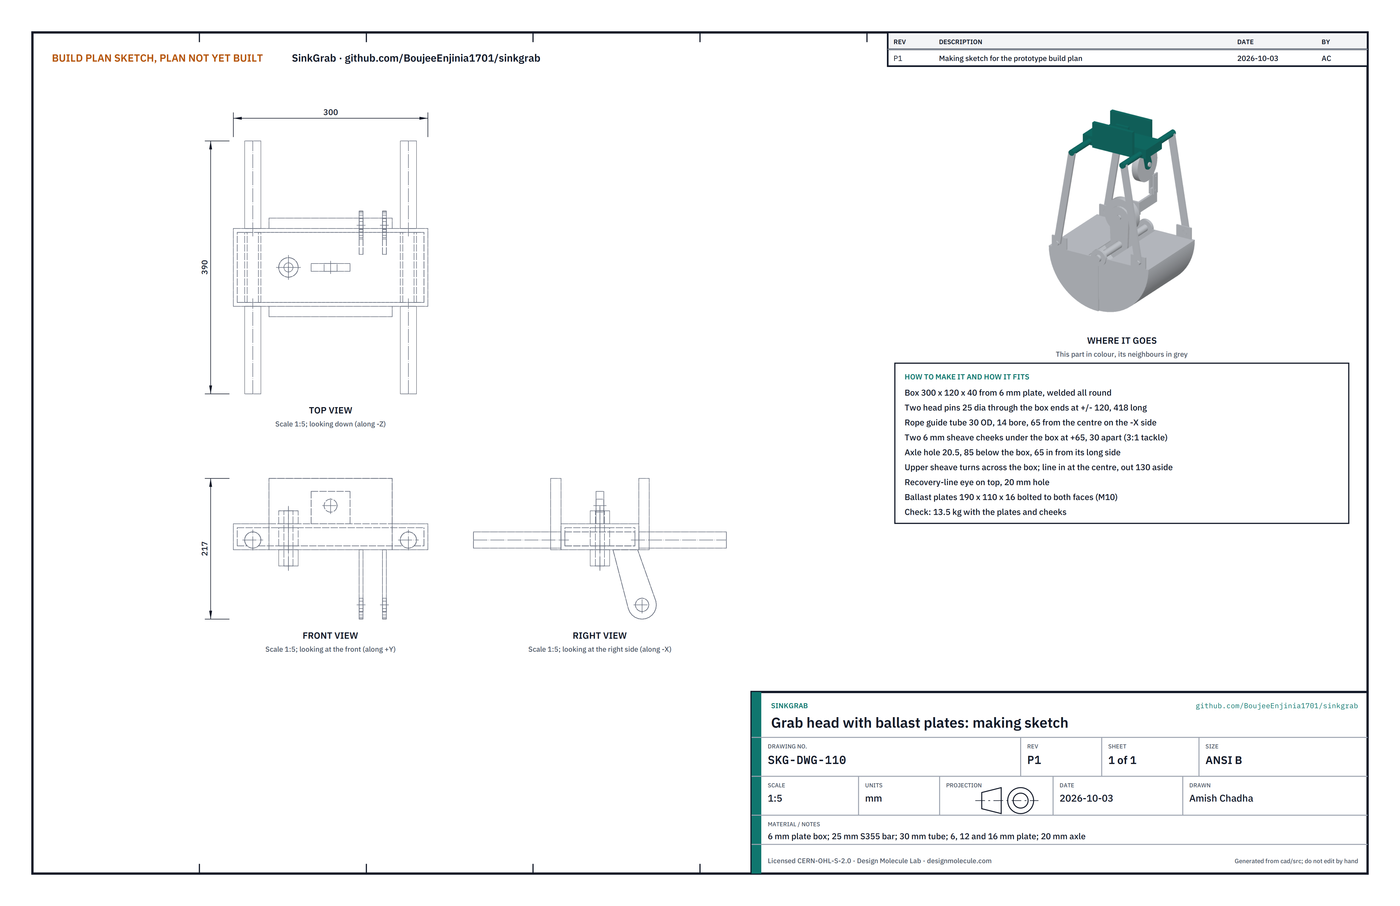
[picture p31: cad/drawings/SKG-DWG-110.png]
Figure 17. Making sketch of the grab head


*Figure 17. Grab head with ballast plates making sketch (SKG-DWG-110).*

**What it is and what it is made from.** The heavy top block that holds the tie rods, guides the line and carries the upper sheave of the tackle. 6 mm plate; 25 mm bright bar; 30 mm tube; 12 mm plate; two 16 mm ballast plates; M10 bolts; the bought upper sheave on a 20 mm axle.

**How to make it.**

1. Weld a box 300 x 120 x 40 from 6 mm plate.
2. Pass the two 25 mm head pins (418 long) through the box ends, 240 mm apart, and weld; drill each end for an R-clip.
3. Weld the rope guide tube (30 mm outside, 14 mm bore) through the box 65 mm from the centre; flare its bottom end.
4. Weld two 6 mm cheek plates under the box, 65 mm the other side of the centre and 30 mm apart, hanging down to a 20.5 mm axle hole 85 mm below the box and 65 mm in from the box's long side. Weld the recovery-line eye on top.
5. Fit the upper sheave between the cheeks on its 20 mm axle with R-clips. It stands across the box, turned 90 degrees to the crosshead sheave, so the line comes up into it on the centre line and goes down again 130 mm to one side.
6. Drill both faces and the ballast plates for M10 bolts.

**Check before moving on.** About 13.5 kg with both plates and the cheeks, and 2.3 kg more with the sheave and axle; the 8 mm line runs freely through the guide and over the upper sheave.

### 3.13 Crosshead, tie rods and shear link

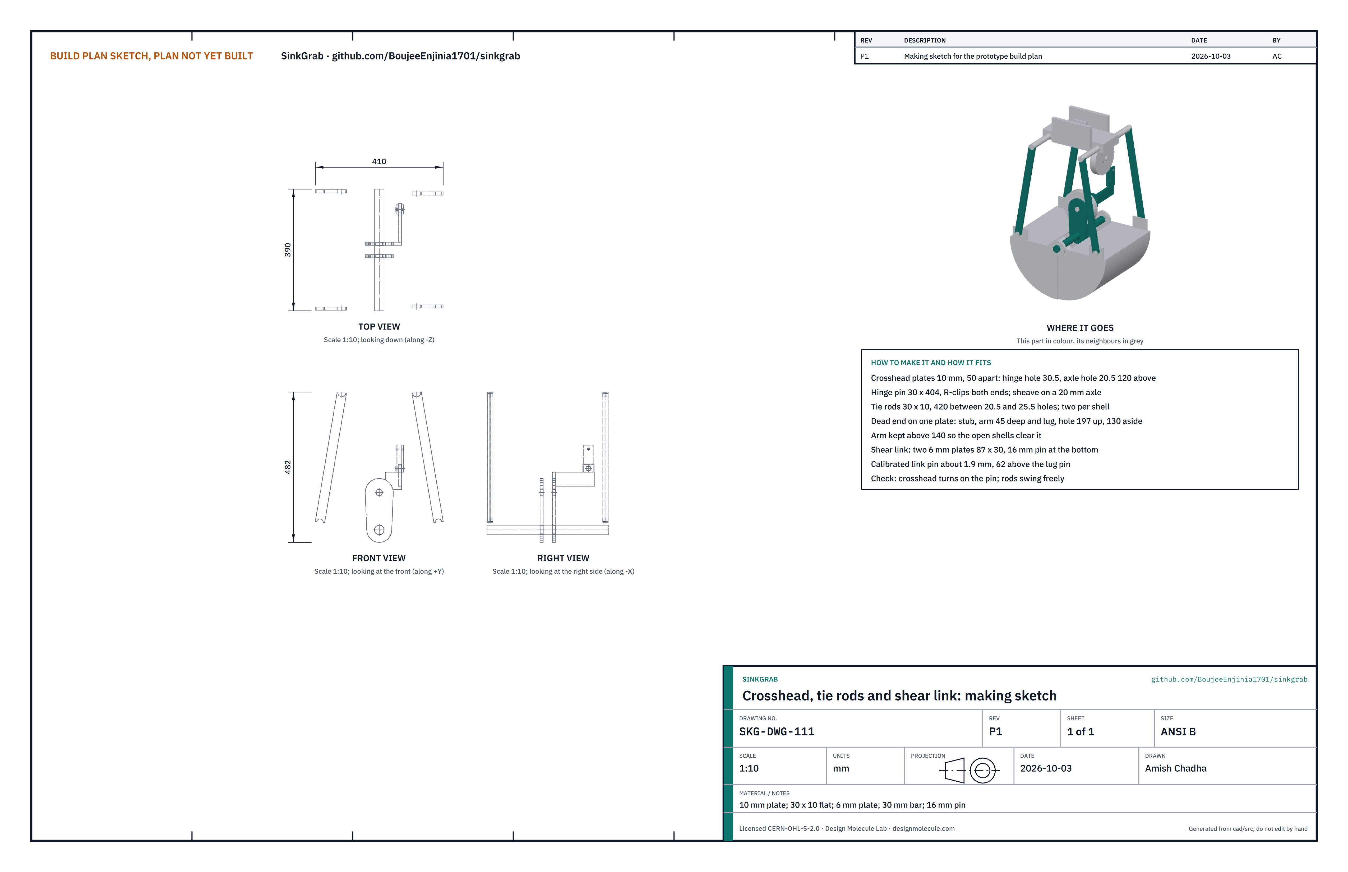
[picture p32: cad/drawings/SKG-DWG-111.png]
Figure 18. Making sketch of the crosshead, tie rods and shear link


*Figure 18. Crosshead, tie rods and shear link making sketch (SKG-DWG-111).*

**What it is and what it is made from.** The crosshead carries the hinge pin, the lower sheave of the tackle and the dead end of the line; the four tie rods join the head to the shells; the shear link is the weak point of the tackle. 10 mm plate; 30 mm bar; 30 x 10 mm flat; 6 mm plate; 16 mm pin; calibrated link pins of about 1.9 mm.

**How to make it.**

1. Cut the two crosshead plates with a 30.5 mm hinge hole and a 20.5 mm axle hole 120 mm above it.
2. On one plate weld the dead end: a 10 mm stub plate running out sideways from the plate, a 10 mm arm plate 45 mm deep along the hinge direction to 150 mm from the centre, and a 10 mm lug on its end with a 16.5 mm hole 197 mm above the hinge and 130 mm from the centre. Keep the arm above 140 mm so the open shells clear it.
3. Cut the hinge pin 404 mm long from 30 mm bar; drill both ends for R-clips.
4. Cut four tie rods 30 x 10 with 20.5 and 25.5 mm holes 420 mm apart.
5. Cut the two link plates 87 x 30 from 6 mm plate with a 16.5 mm hole at the bottom and a 6.5 mm hole 62 mm above it; the link pin goes through a bush in the small hole so the pin can be swapped.

**How it fits the parts next to it.**

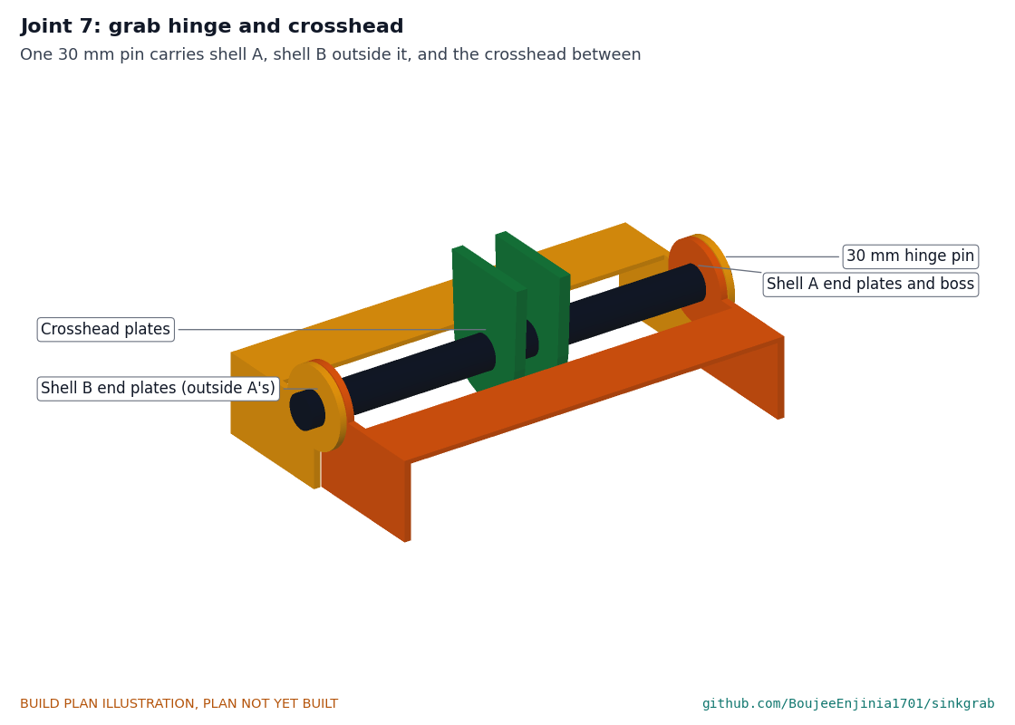
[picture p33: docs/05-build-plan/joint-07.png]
Figure 19. Joint 7: grab hinge and crosshead


*Figure 19. Joint 7. One 30 mm pin carries shell A's end plates, shell B's end plates outside them, and the two crosshead plates between. The sheave (not shown) turns on its own axle 120 mm above the pin.*

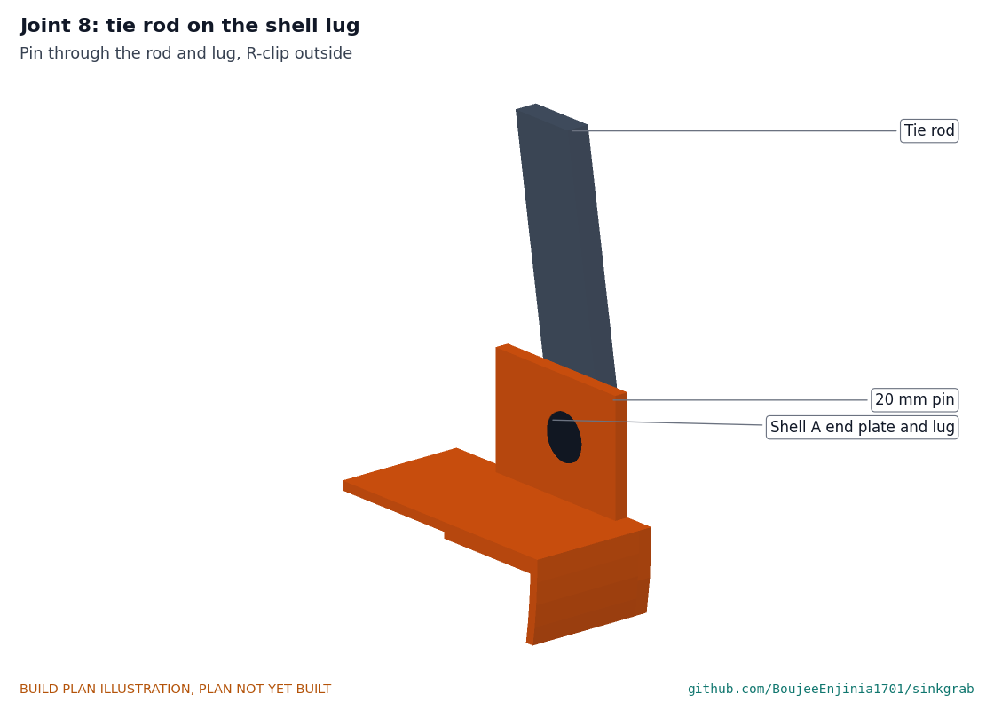
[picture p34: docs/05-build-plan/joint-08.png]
Figure 20. Joint 8: tie rod on the shell lug


*Figure 20. Joint 8. Each tie rod is pinned to its shell's lug with a 20 mm pin and R-clip; shell A's rods run outside A's end plates, shell B's outside B's.*

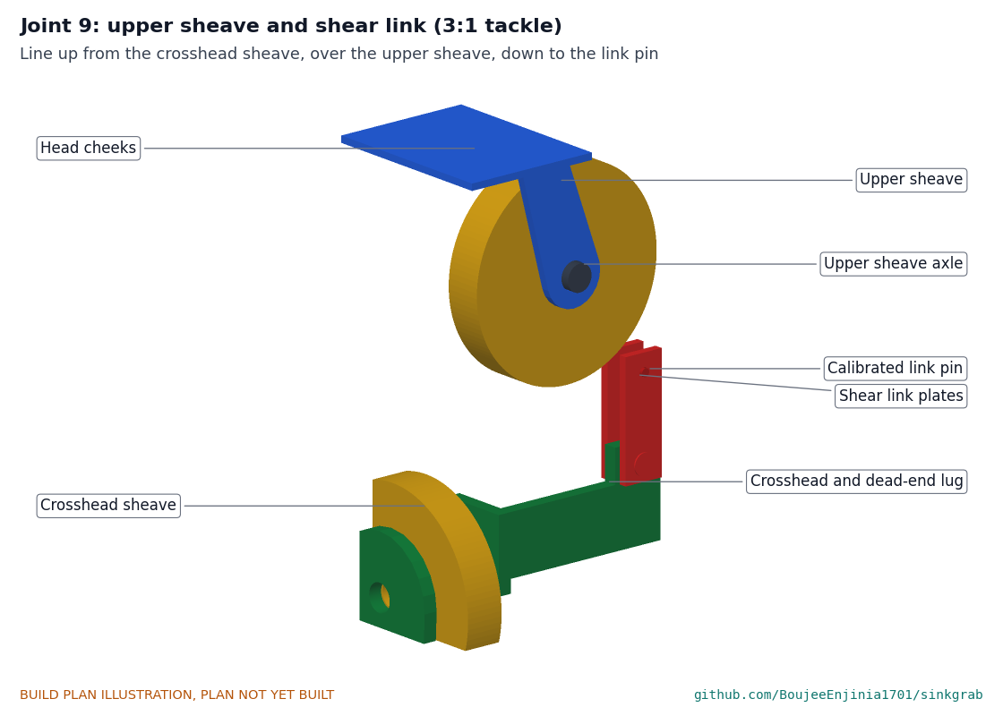
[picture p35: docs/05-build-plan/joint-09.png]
Figure 21. Joint 9: upper sheave and shear link


*Figure 21. Joint 9. The line comes up from the crosshead sheave, over the upper sheave in the head and down to the shear link on the crosshead's dead-end lug; its thimble hangs on the small calibrated pin. Three parts of line between head and crosshead close the shells 50 % harder than two. If the grab snags and the line pulls more than about 1.2 to 1.5 kN, the pin shears, the line runs out over both sheaves and the grab opens.*

**Check before moving on.** The crosshead turns on the pin; the rods swing freely; a test link pin from the same coil has been broken at the right load (see the register).

### 3.14 Scraper head

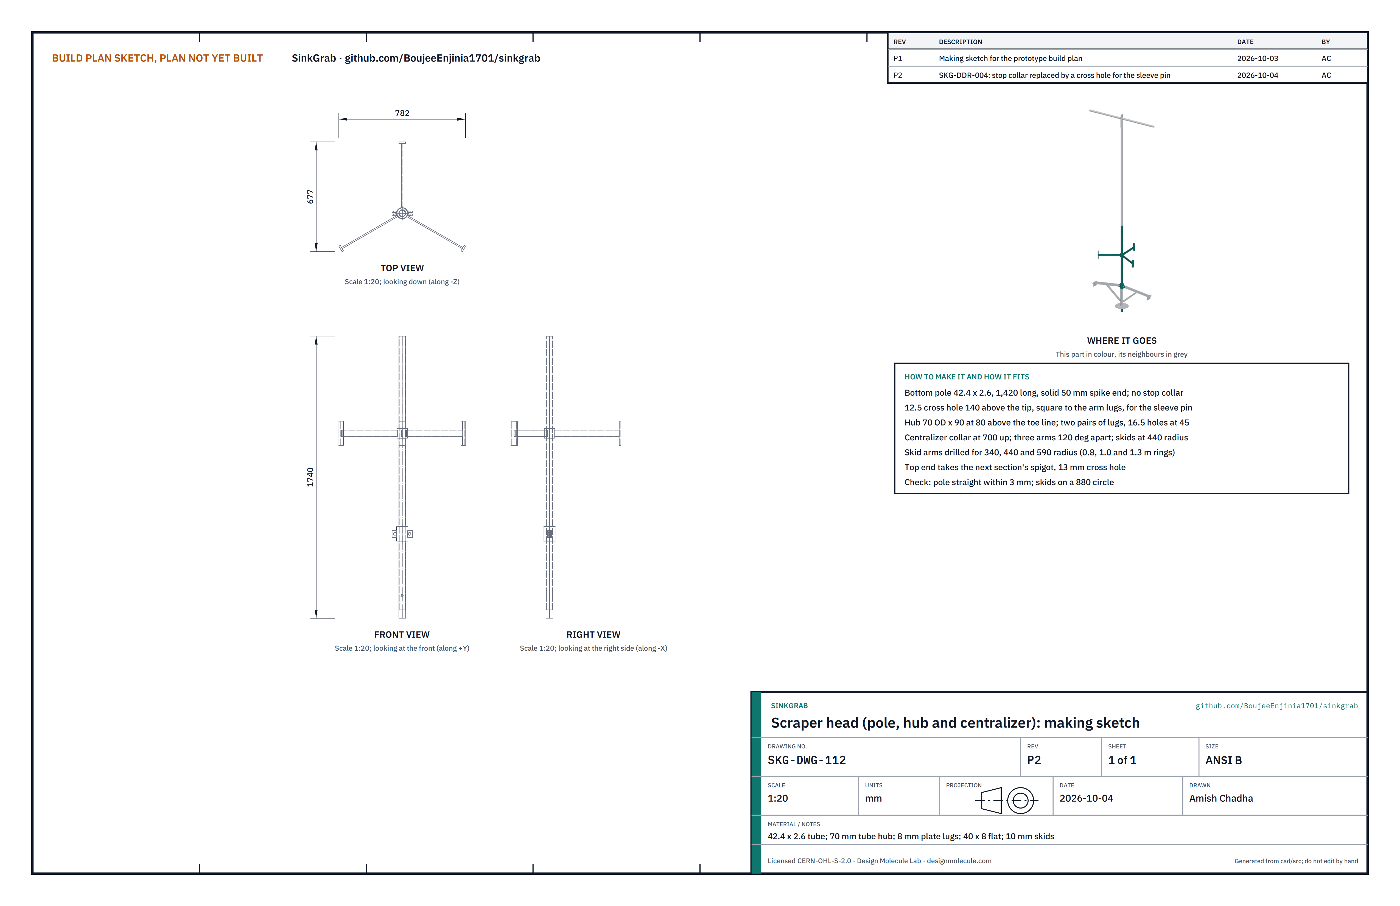
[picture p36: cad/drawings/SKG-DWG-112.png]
Figure 22. Making sketch of the scraper head


*Figure 22. Scraper head (pole, hub and centralizer) making sketch (SKG-DWG-112).*

**What it is and what it is made from.** The bottom pole section that carries the arms and centres itself in the ring. 42.4 x 2.6 mm tube; 50 mm bar for the spike; 70 mm tube for the hub; 8 mm plate lugs; 40 x 8 flat; 10 mm skid plates.

**How to make it.**

1. Cut the pole 1,420 mm and weld a 50 mm solid spike in the bottom end. Drill a 12.5 mm cross hole through the pole 140 mm above the tip, square to the arm lugs, for the sleeve's cross pin. There is no stop collar: the pin stops the sleeve.
2. Weld the hub 80 mm above the toe line, with two pairs of 8 mm lugs either side, 16.5 mm holes 45 mm off the pole axis.
3. Weld the centralizer collar 700 mm up with three arms 120 degrees apart; drill each arm for the skids at 340, 440 and 590 mm radius; bolt the skids at 440 for a 1.0 m ring.
4. Drill a 13 mm cross hole 75 mm below the top end for the next section's bolt.

**Check before moving on.** Straight within 3 mm; the skids lie on an 880 mm circle.

### 3.15 Scraper arms, struts and sleeve

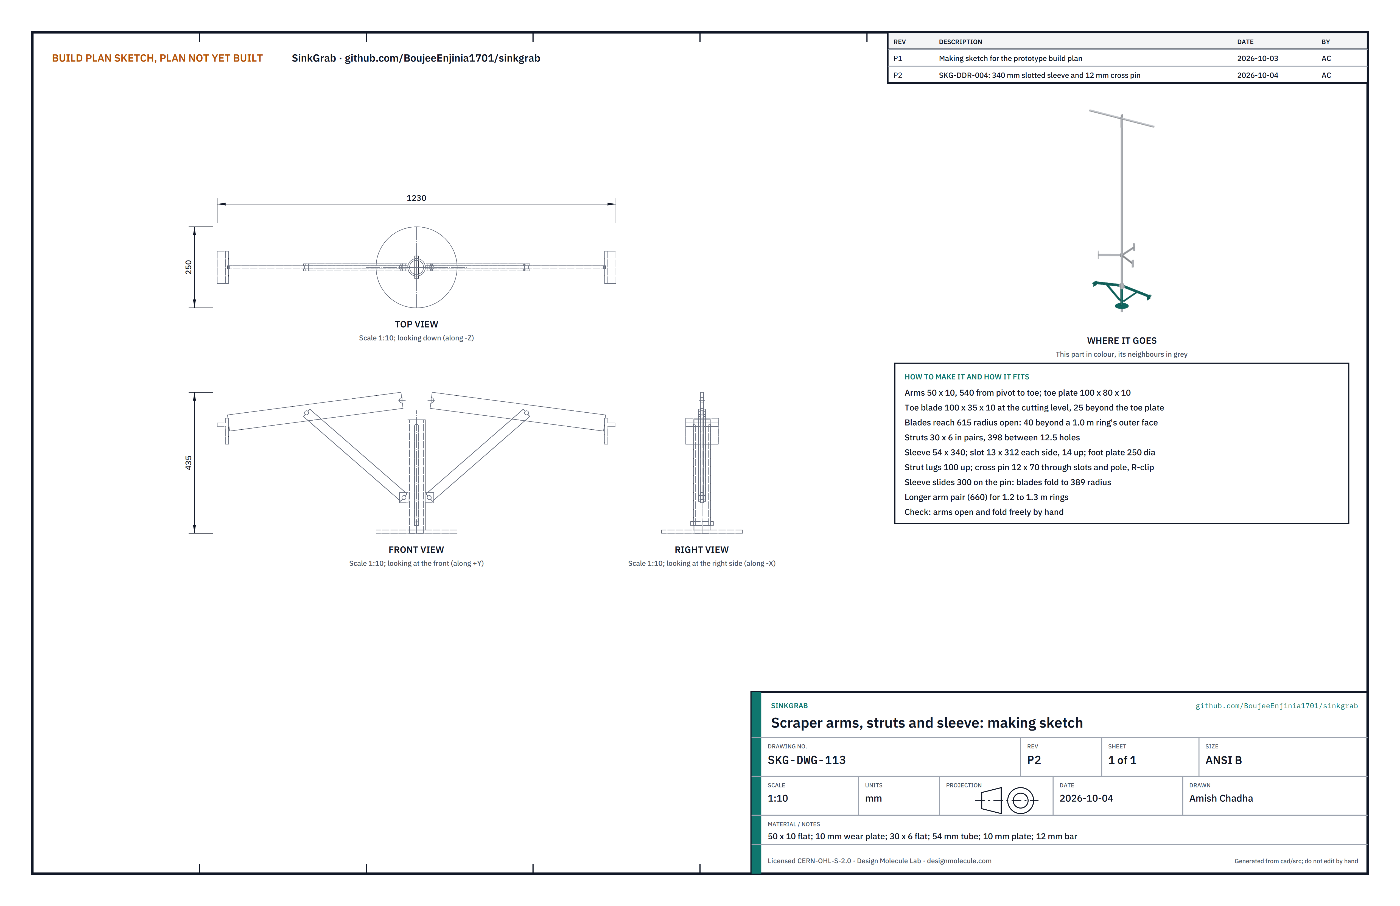
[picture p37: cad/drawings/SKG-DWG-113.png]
Figure 23. Making sketch of the scraper arms, struts and sleeve


*Figure 23. Scraper arms, struts and sleeve making sketch (SKG-DWG-113).*

**What it is and what it is made from.** Two arms whose toes cut under the ring and 40 mm beyond its outer face, opened by the pole's weight, and the slotted sleeve that lets them fold to pass the ring. 50 x 10 mm flat; 10 mm wear-resistant plate for the toes and toe blades; 30 x 6 mm flat for the struts; 54 mm tube and a 250 mm, 10 mm disc for the sleeve and foot; 12 mm bright bar for the cross pin; 12 and 16 mm pins.

**How to make it.**

1. Cut two arms 540 mm from pivot hole to toe; weld a toe plate 100 x 80 x 10 square across each end.
2. Cut two toe blades 100 x 35 from 10 mm wear-resistant plate. Weld one under the end of each arm at the cutting level, lapped 10 mm on the arm and toe plate and standing 25 mm out beyond the toe plate, so the blade's edge is 615 mm from the pole axis.
3. Drill each arm for its 16 mm pivot pin and, 339 mm out, a 12.5 mm strut pin.
4. Cut four struts 30 x 6 with 12.5 mm holes 398 mm apart.
5. Cut the sleeve 340 mm long from 54 mm tube. Cut a slot 13 mm wide and 312 mm long through each side, starting 14 mm above the bottom end, with the top of each slot rounded; the two slots face each other. Weld the foot disc under the sleeve, and a 10 mm strut lug on each of the other two sides, 100 mm above the bottom, with a 12.5 mm hole.
6. Cut the cross pin 70 mm long from 12 mm bright bar and drill a small hole near one end for an R-clip.
7. For 1.2 to 1.3 m rings, make a second pair of arms 660 mm long, with the same blades.

**How it fits the parts next to it.**

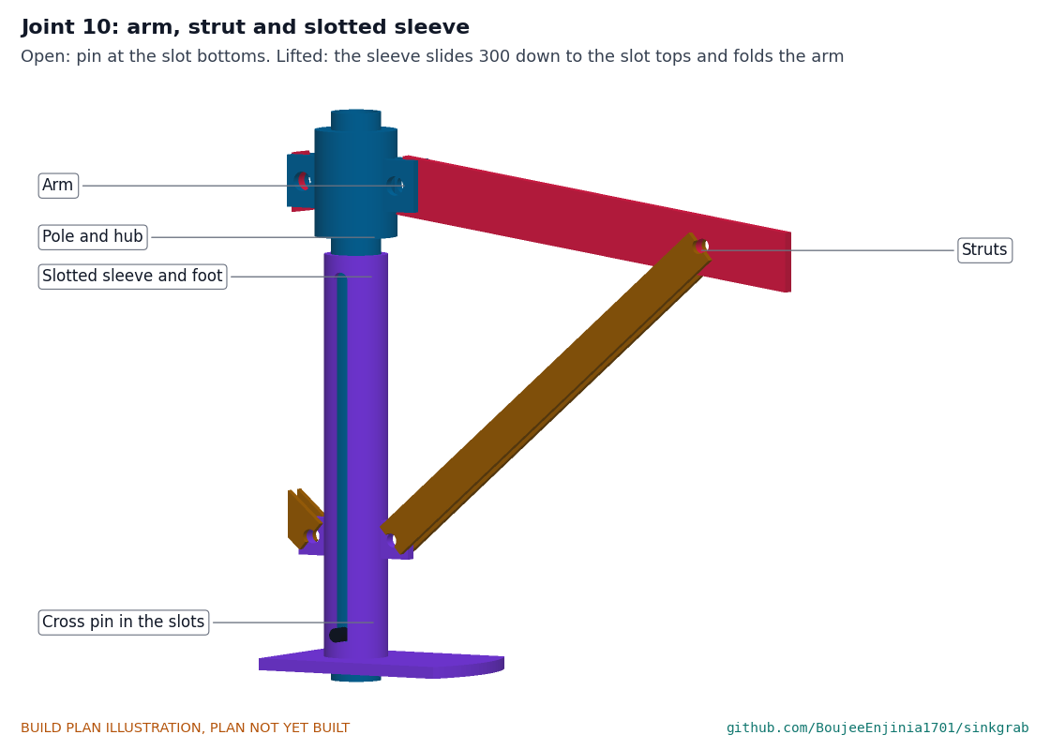
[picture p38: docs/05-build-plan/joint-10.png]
Figure 24. Joint 10: arm, strut and sliding sleeve


*Figure 24. Joint 10. The sleeve slides on the pole, held by a cross pin through the pole that runs in a slot on each side of the sleeve. When the foot rests on the sump floor and the line is slacked, the pole slides down through the sleeve until the pin reaches the bottom of the slots, and the struts push the arms out.*

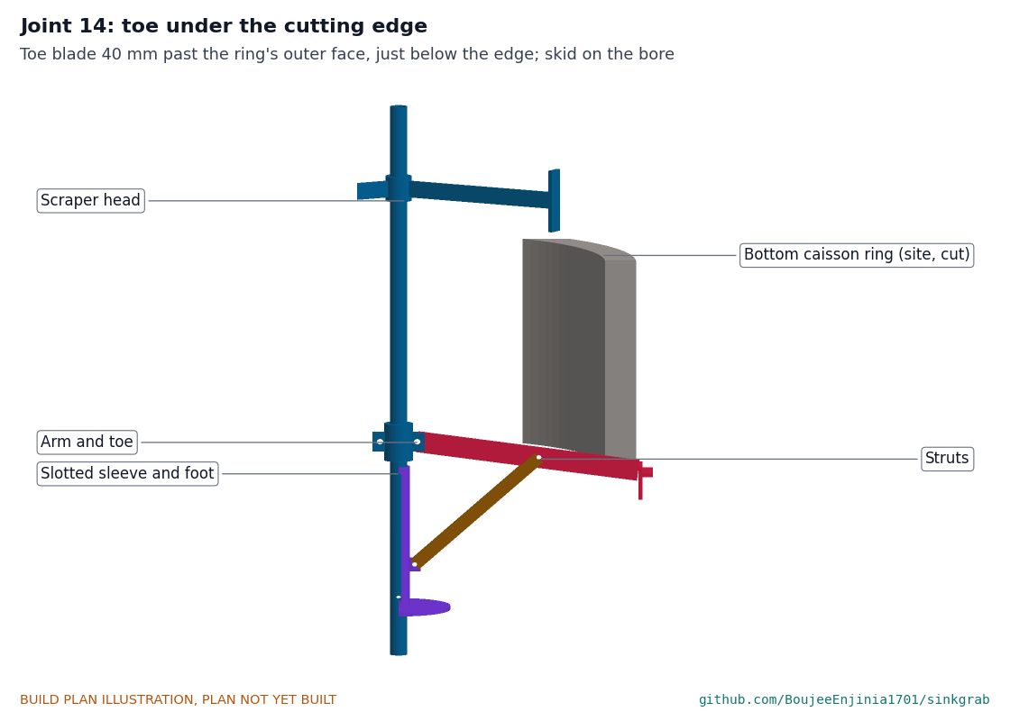
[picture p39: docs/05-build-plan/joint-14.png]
Figure 25. Joint 14: toe under the cutting edge


*Figure 25. Joint 14, the ring cut away. Open, the toe blade reaches 40 mm past the ring's outer face, just below its cutting edge, so the ring slides down through loosened soil; the skid bears on the bore above. Lifting the pole lets the sleeve slide 300 mm down it until the pin reaches the top of the slots; that folds the blades to 389 mm radius so the head passes the ring.*

**Check before moving on.** The arms open and fold freely by hand by sliding the sleeve the full length of its slots; folded, the blades sit inside an 800 mm circle. The head weighs about 26.1 kg with the arms on, so unpin the two arms for carrying: about 20.1 kg for the head and 6.0 kg for the arms.

### 3.16 Pole sections and T-bar

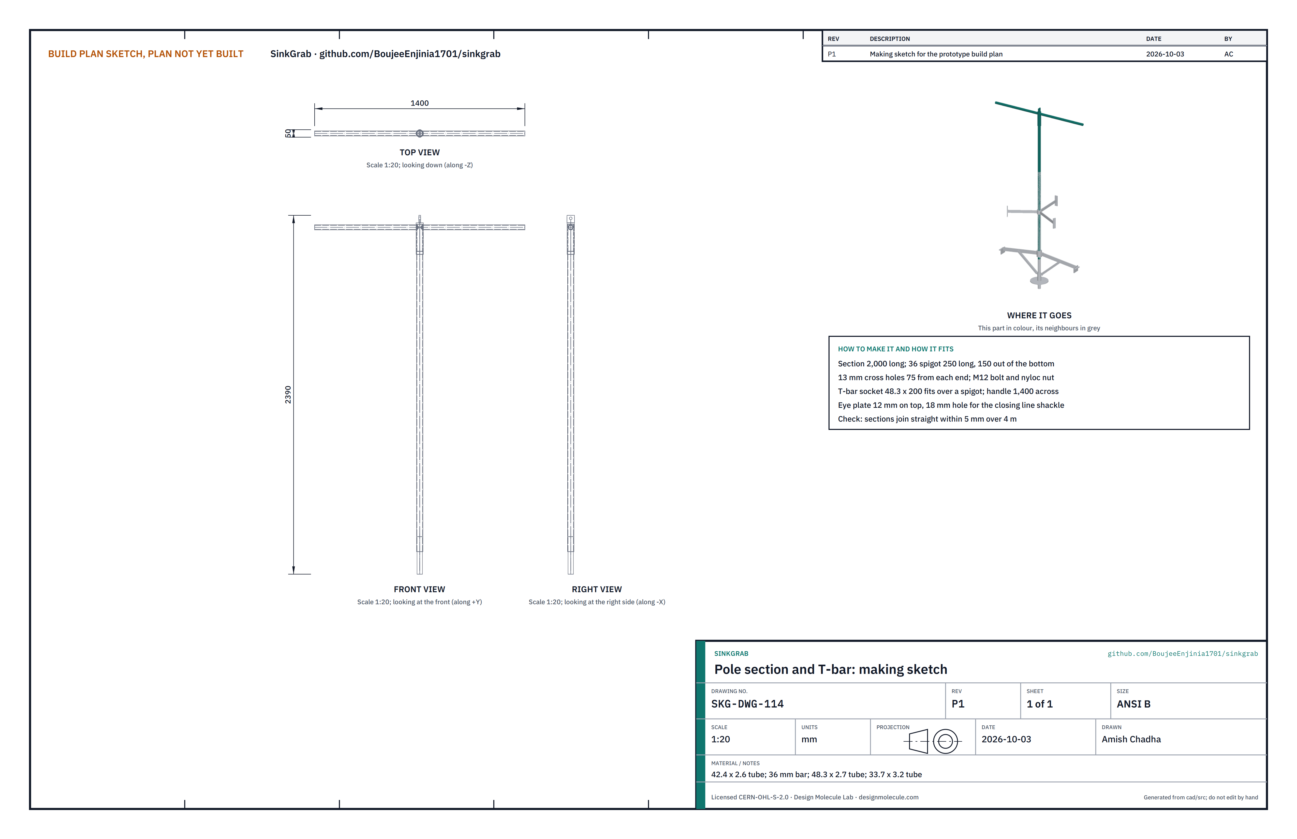
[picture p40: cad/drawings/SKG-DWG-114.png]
Figure 26. Making sketch of the pole section and T-bar


*Figure 26. Pole section and T-bar making sketch (SKG-DWG-114).*

**What it is and what it is made from.** 2 m extensions and the handle. 42.4 x 2.6 mm tube; 36 mm bar; 48.3 x 2.7 mm tube; 33.7 x 3.2 mm tube; 12 mm plate; M12 bolts.

**How to make it.** Cut each section 2,000 mm; weld a 36 mm spigot 250 mm long into the bottom end, 150 mm out; drill 13 mm cross holes 75 mm from each end. For the T-bar, weld the 1,400 mm handle across a 200 mm socket of 48.3 tube and the eye plate on top.

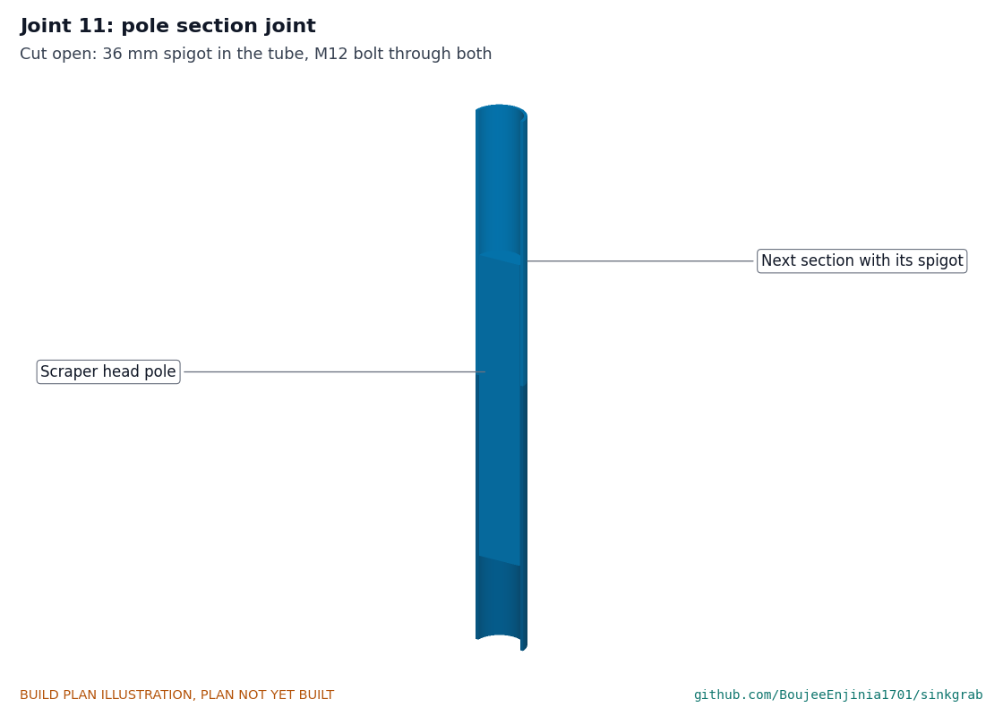
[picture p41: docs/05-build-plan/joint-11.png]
Figure 27. Joint 11: pole section joint


*Figure 27. Joint 11, cut open. The spigot slides into the tube below; one M12 bolt through both carries the weight and the turning.*

**Check before moving on.** Two sections bolted together are straight within 5 mm over 4 m.

### 3.17 Well-head frame

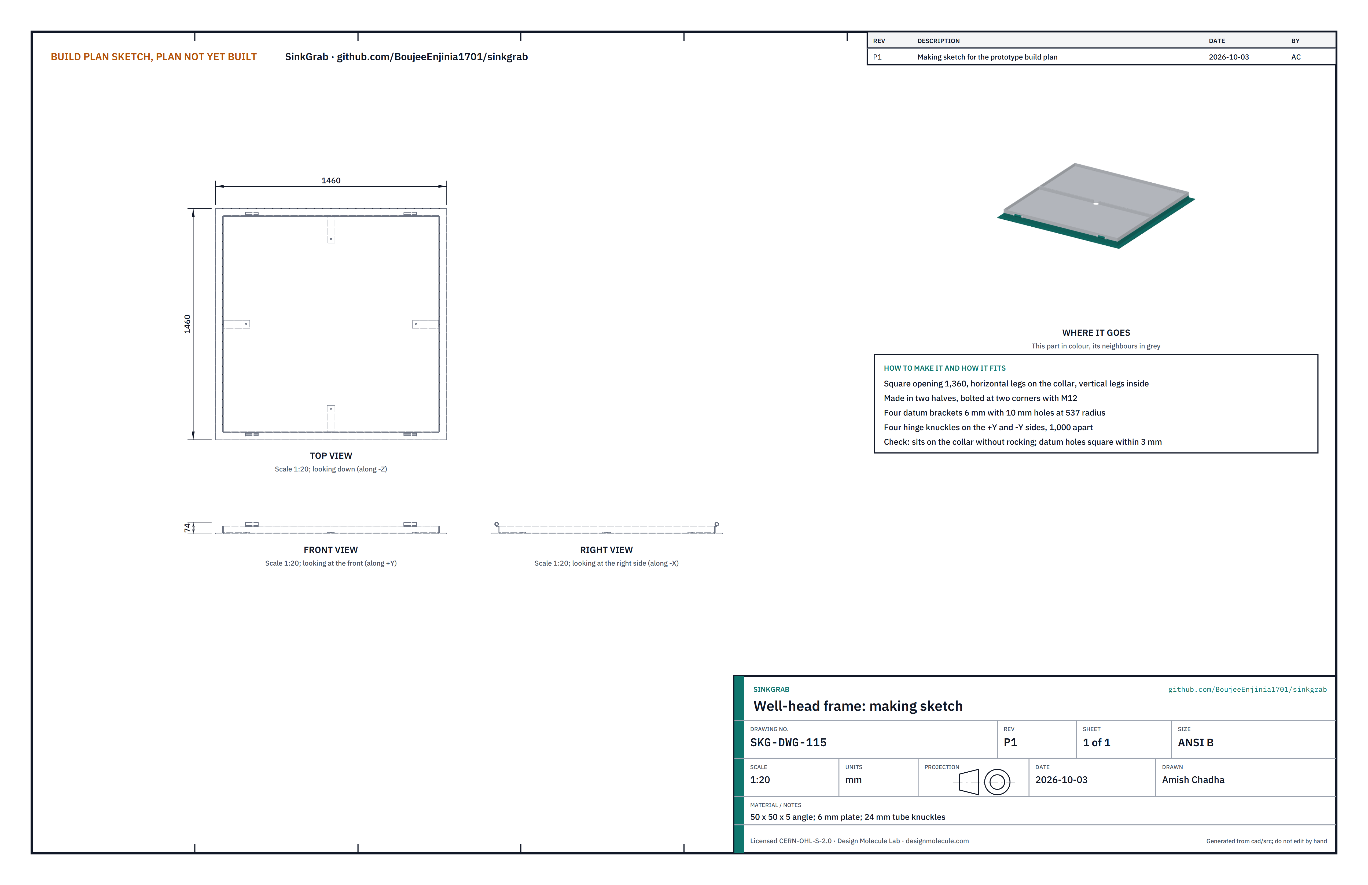
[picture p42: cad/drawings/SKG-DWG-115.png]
Figure 28. Making sketch of the well-head frame


*Figure 28. Well-head frame making sketch (SKG-DWG-115).*

**What it is and what it is made from.** A square frame that sits on the well collar and carries the doors and the tilt datum. 50 x 50 x 5 mm angle; 6 mm plate; 24 mm tube for the hinge knuckles; M12 bolts.

**How to make it.**

1. Cut and weld the angle into two L-shaped halves that bolt at two corners into a frame with a 1,360 mm square opening, horizontal legs out and down onto the collar, vertical legs up at the inner edge.
2. Weld four datum brackets (6 mm plate) under the frame at the middle of each side, each with a 10 mm hole 537 mm from the centre, over the caisson ring wall.
3. Weld two hinge knuckles on each of the two hinged sides, 1,000 mm apart.

**Check before moving on.** It sits on the collar without rocking; the four datum holes lie on a square within 3 mm.

### 3.18 Folding doors (make 2)

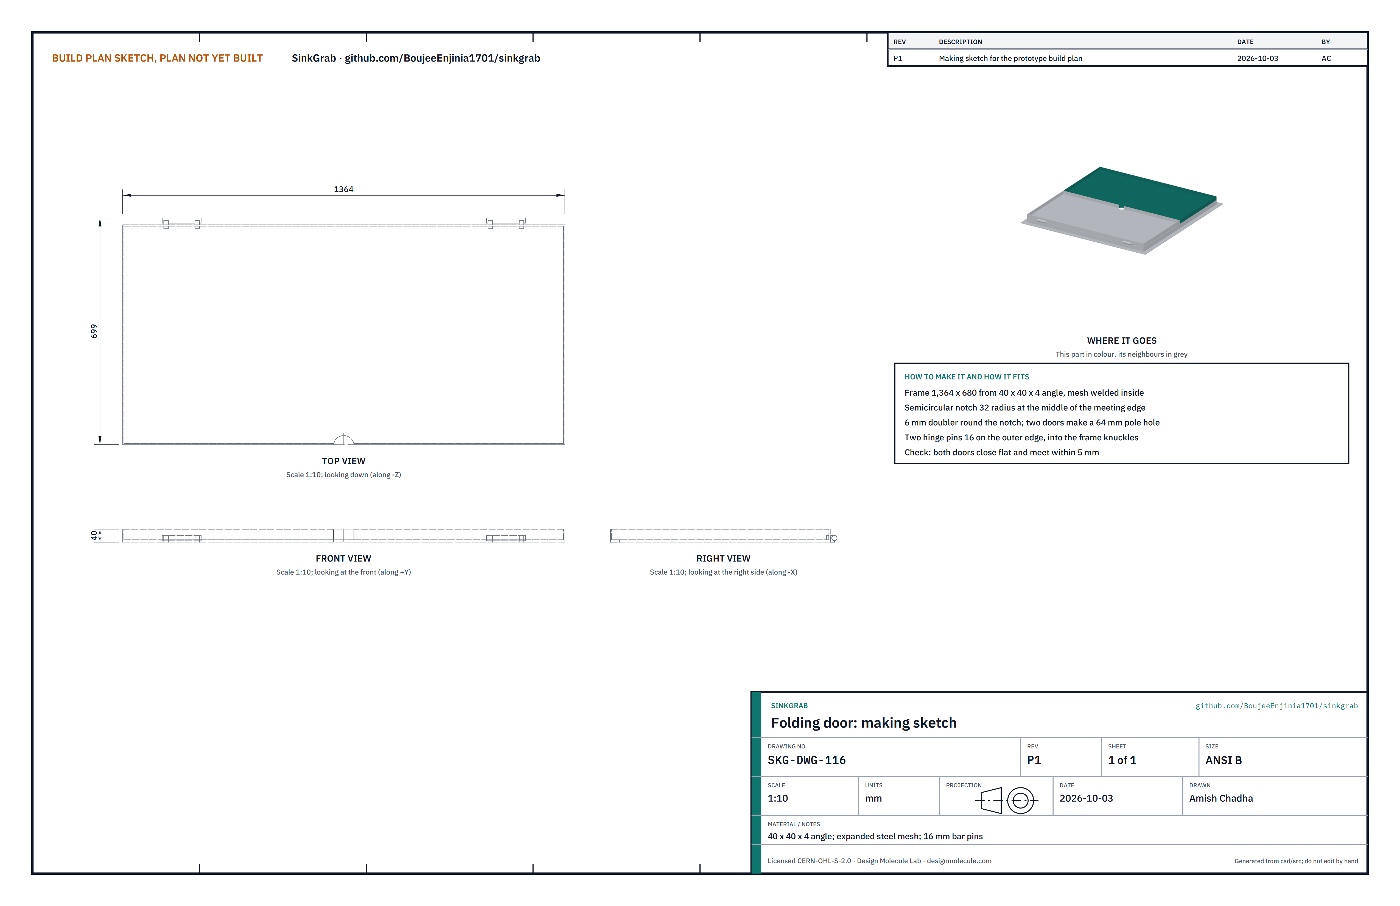
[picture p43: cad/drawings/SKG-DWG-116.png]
Figure 29. Making sketch of a folding door


*Figure 29. Folding door making sketch (SKG-DWG-116).*

**What it is and what it is made from.** Two mesh doors that close over the shaft. 40 x 40 x 4 mm angle; expanded steel mesh; 6 mm plate doubler; 16 mm bar.

**How to make it.** Weld a frame 1,364 x 680 from angle with the mesh inside. Cut a 32 mm radius notch at the middle of the meeting edge and weld a 6 mm doubler round it. Weld two hinge pins on the outer edge to match the knuckles.

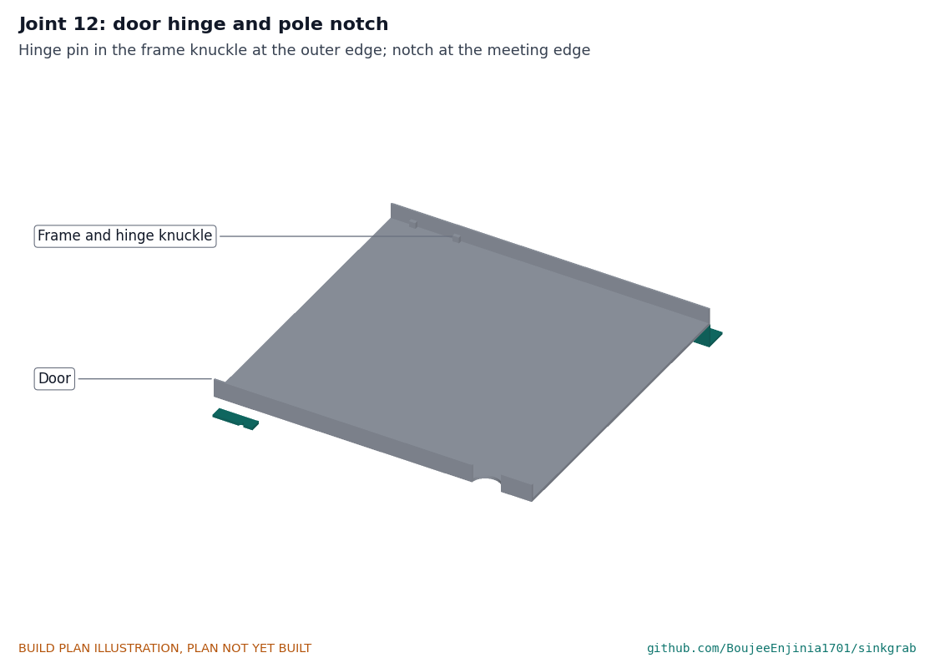
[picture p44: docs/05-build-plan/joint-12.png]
Figure 30. Joint 12: door hinge and pole notch


*Figure 30. Joint 12. Each door hinges on two pins in the frame knuckles at its outer edge and rests on the frame's vertical legs. Closed, the two notches make a 64 mm hole for the pole.*

**Check before moving on.** Both doors close flat and meet within 5 mm; each is about 18 kg.

### 3.19 Ballast saddles (make 8)

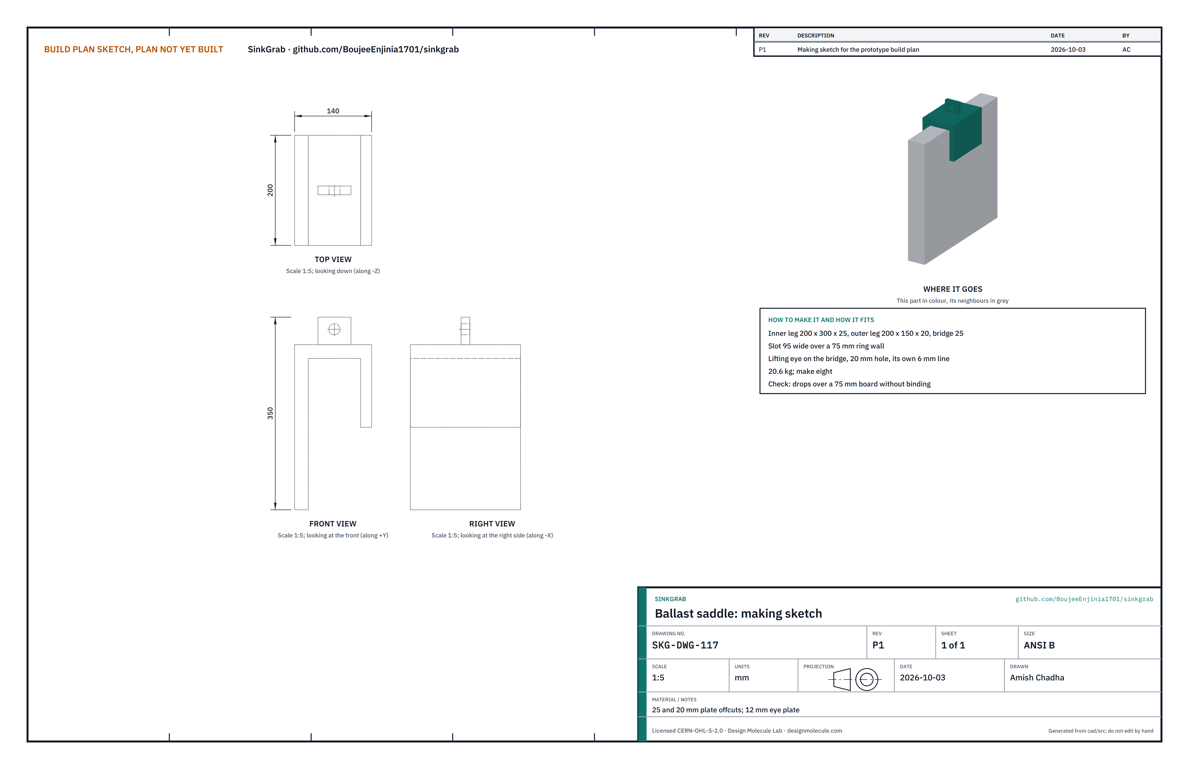
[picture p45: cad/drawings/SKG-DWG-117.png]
Figure 31. Making sketch of a ballast saddle


*Figure 31. Ballast saddle making sketch (SKG-DWG-117).*

25 and 20 mm plate offcuts welded into a U: inner leg 200 x 300 x 25, outer leg 200 x 150 x 20, bridge 25 mm, a 95 mm slot, and a lifting eye with a 20 mm hole for its own 6 mm line. About 20.6 kg each.

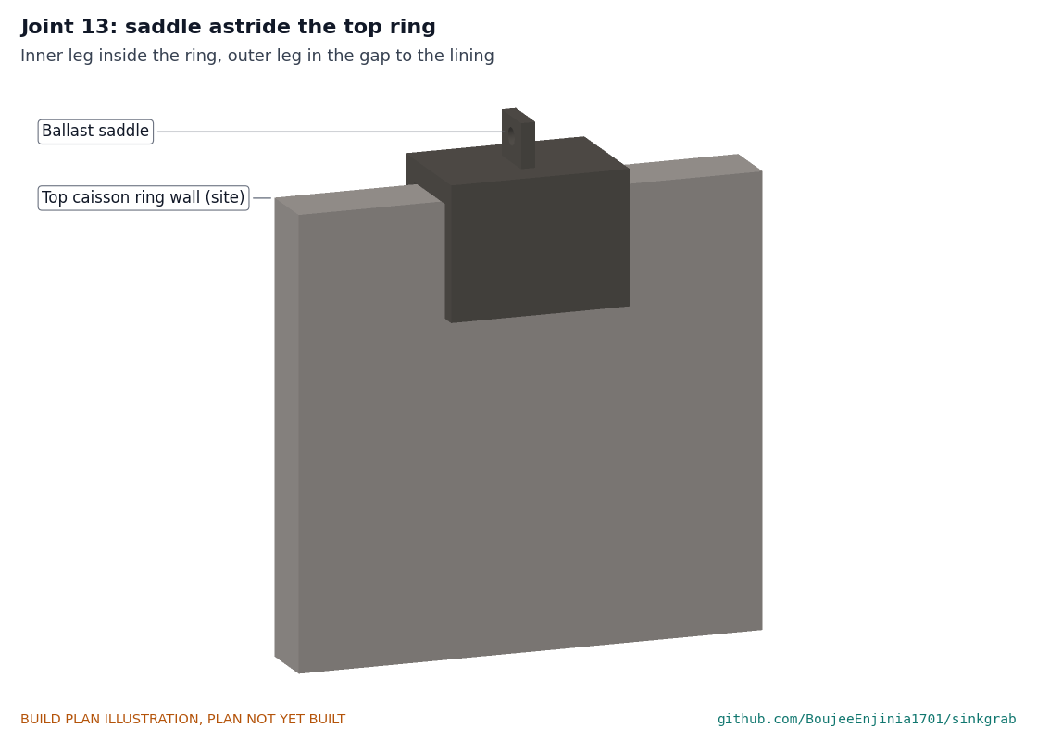
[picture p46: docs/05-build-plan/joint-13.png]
Figure 32. Joint 13: saddle astride the top ring


*Figure 32. Joint 13. The saddle drops over the ring wall: the inner leg inside the ring, the outer leg in the gap to the lining.*

**Check before moving on.** It drops over a 75 mm board without binding.

### 3.20 Bought components

Buy to specification, not brand. Line numbers are those of the bill of materials.

- **Bearings (lines 21 and 22).** Two UCP206 (30 mm) and two UCP205 (25 mm) pillow block ball bearings.
- **Sprockets and chain (line 23).** ISO 08B-1: a 12-tooth sprocket bored to suit the hub and a 48-tooth plate wheel bored 30 mm; 1.6 m of chain, breaking load at least 17.8 kN, with one connecting link.
- **Crank shear pins (line 24).** 3 mm S235 mild steel bar cut 40 mm long, with split pins; never hardened steel.
- **Sheaves (line 25).** Four sheaves 150 mm outside, 130 mm at the rope, grooved for 8 mm fibre rope, 28 mm wide, 20 mm bore with a ball bearing, rated at least 500 kg: one for the cradle, one for the crosshead, one for the grab head (the 3:1 tackle), one to fit in the HatchSide head in place of its wire-rope sheave.
- **Ropes (lines 26 to 28).** 45 m of 8 mm polyester double braid (at least 12 kN) with a thimble eye splice for the closing line; 40 m of 8 mm for the recovery line; eight 32 m lengths of 6 mm braid (at least 5 kN) for the saddles.
- **Rigging (line 29).** A ball-bearing swivel and bow shackles, WLL 500 kg, and one WLL 1,000 kg shackle for the T-bar eye.
- **Dip tape and plumb line (line 30), gas detector (line 31), spoil tubs (line 32), barrier kit and briefing card (line 33), fasteners and consumables (line 34).**

## 4. Putting it together

In each picture the parts already fitted are grey and the part being fitted is in colour, with an arrow showing the way it goes in. Steps 1 to 15 are done in the workshop; steps 16 to 20 at the well. Two people throughout.

### Step 1: drum bearings onto the drum shaft

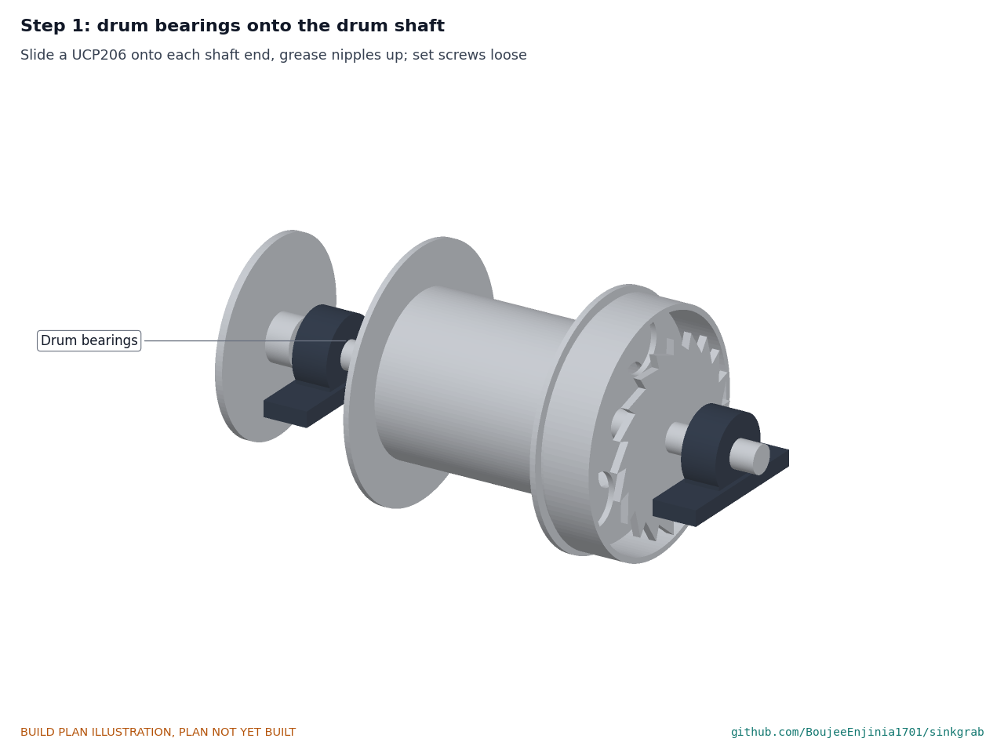
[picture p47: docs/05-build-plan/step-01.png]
Step 1


Slide a UCP206 onto each end of the drum shaft, grease nipples up, set screws loose.

### Step 2: lower the drum onto the pads

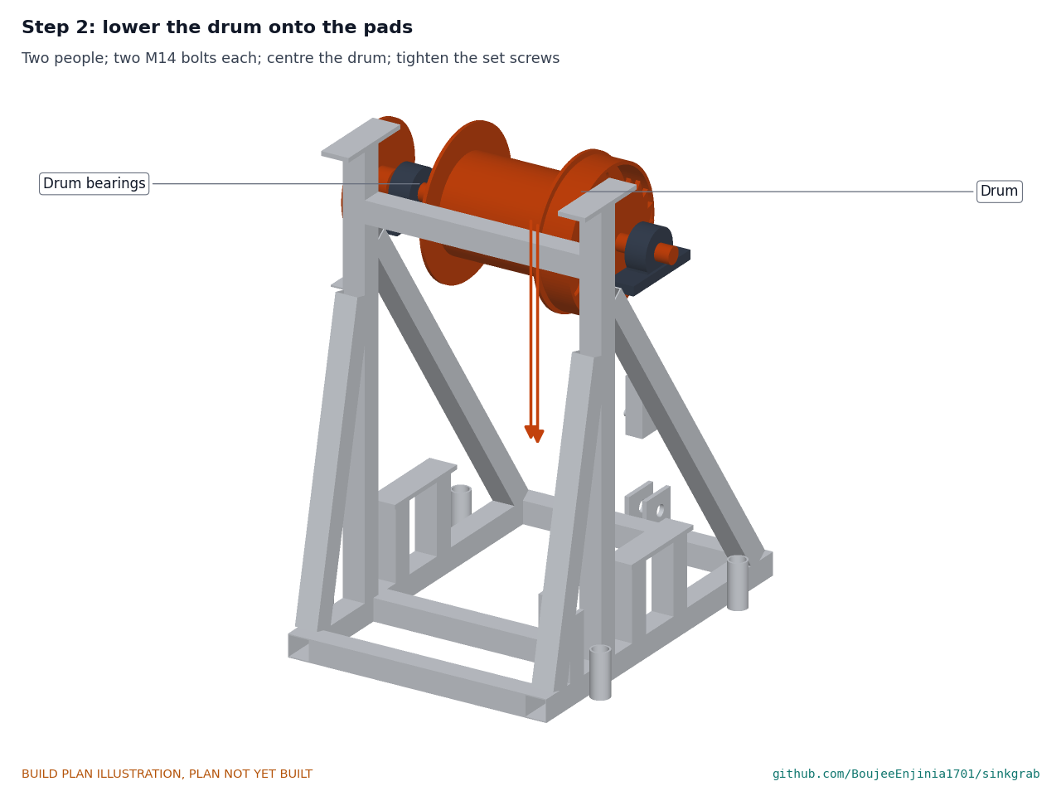
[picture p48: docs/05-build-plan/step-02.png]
Step 2


Two people lower the drum and bearings onto the pads, sprocket to the -X side. Bolt each bearing with two M14 bolts, centre the drum and tighten the set screws.

### Step 3: crank shaft, hub and bearings onto the top plates

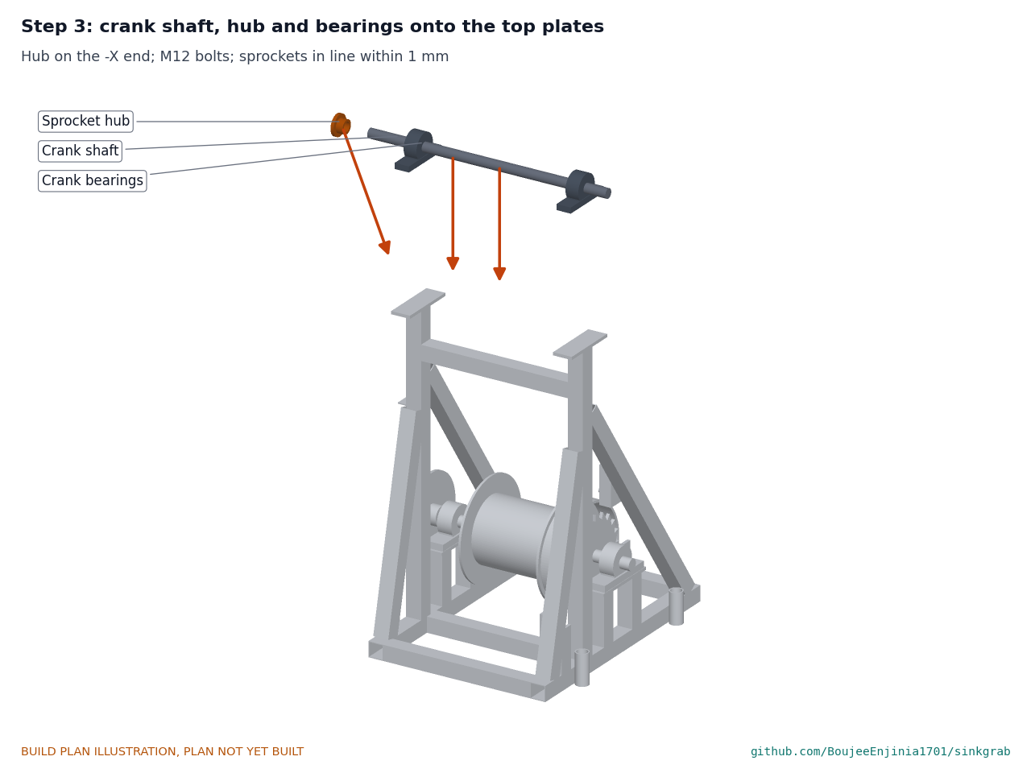
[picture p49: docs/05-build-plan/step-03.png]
Step 3


Slide the crank bearings onto the crank shaft with the sprocket hub on the -X end. Bolt the bearings to the top plates with M12 bolts, the small sprocket in line with the big one within 1 mm.

### Step 4: fit the chain

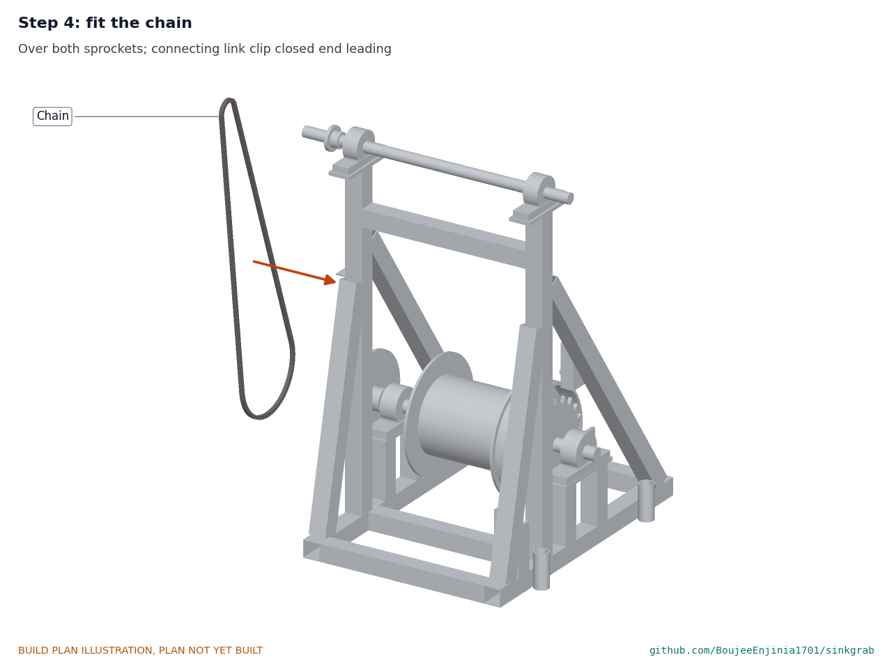
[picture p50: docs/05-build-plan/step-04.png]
Step 4


Lay the chain over both sprockets and join it with the connecting link, the clip's closed end leading when hoisting. It should lift about 10 mm at mid-span.

### Step 5: fit the shear pin

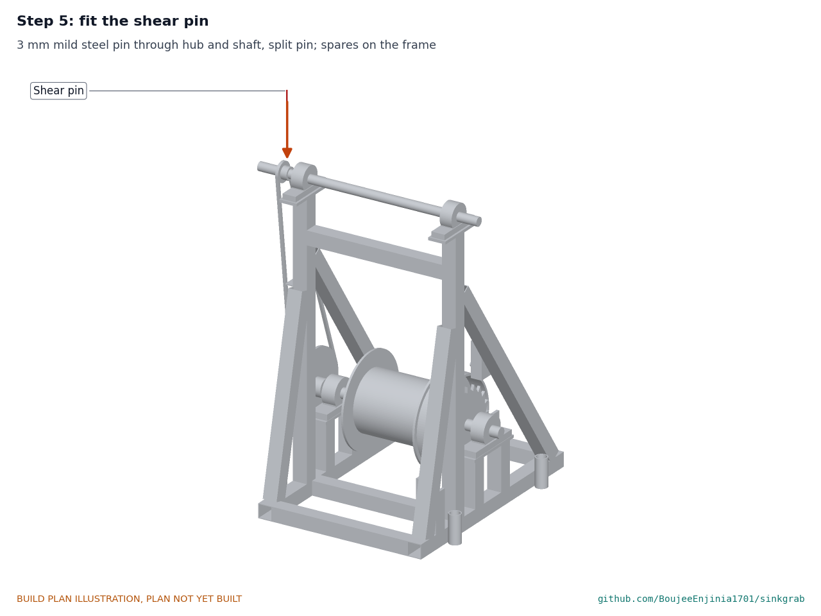
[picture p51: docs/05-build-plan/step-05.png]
Step 5


Push a 3 mm shear pin through the hub and shaft and fit its split pin. Hang spares on the frame.

### Step 6: chain guard on

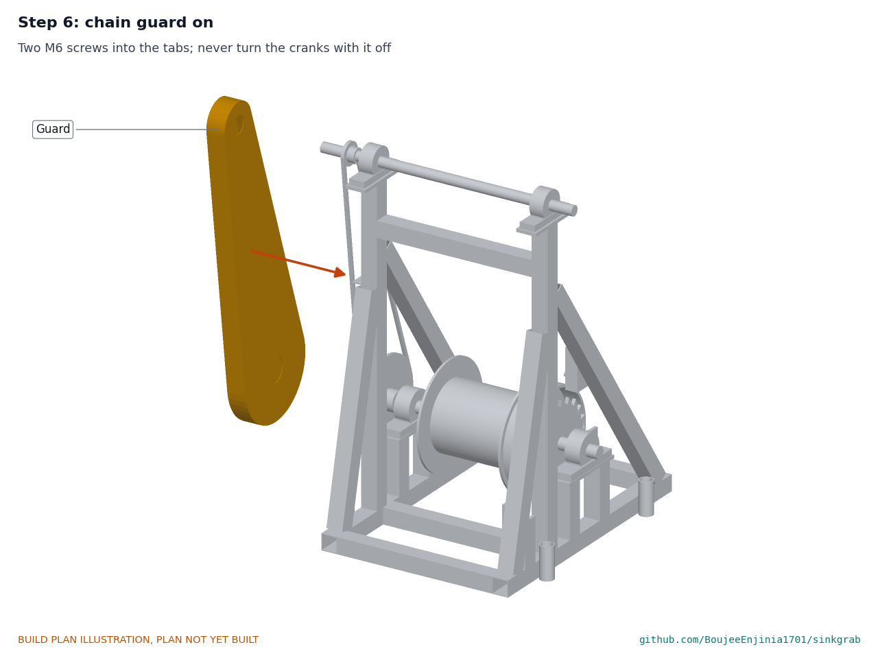
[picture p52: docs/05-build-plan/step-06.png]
Step 6


Fit the guard and fix it with two M6 screws. From now on the cranks are never turned with it off.

### Step 7: pawl on its pin

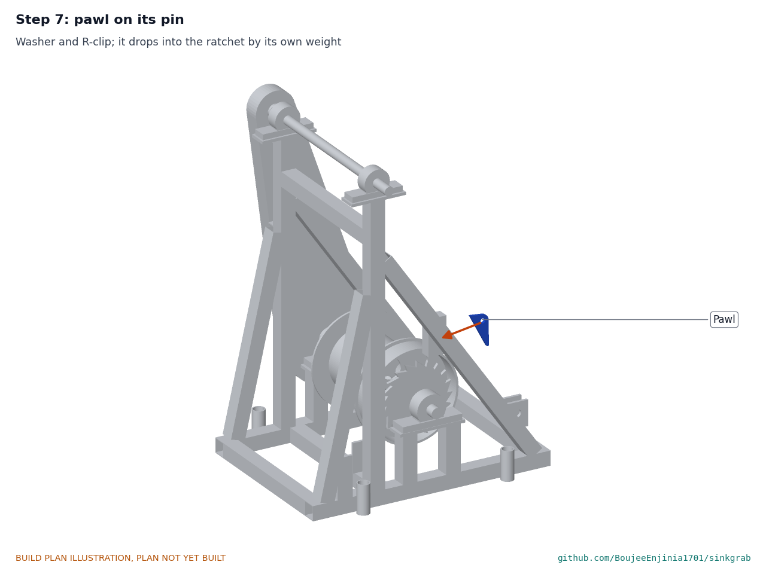
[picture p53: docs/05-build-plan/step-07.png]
Step 7


Hang the pawl on its pin with a washer and R-clip; check it drops into the ratchet.

### Step 8: band brake and weighted lever

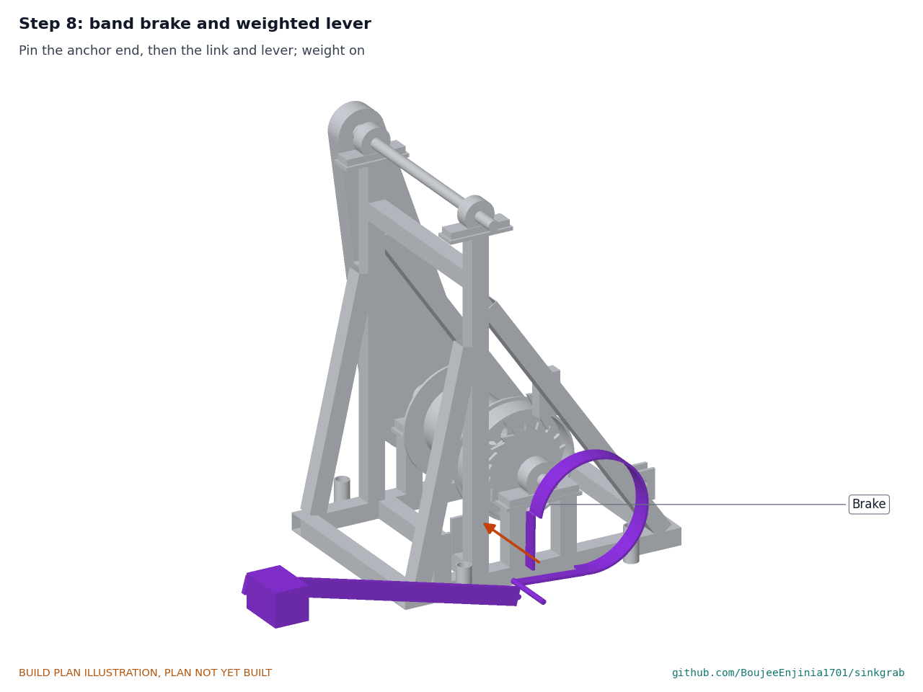
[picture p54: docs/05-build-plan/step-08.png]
Step 8


Wrap the band round the brake drum, pin the anchor end, then the link and lever; fit the weight. Check the drum is held.

### Step 9: cranks on

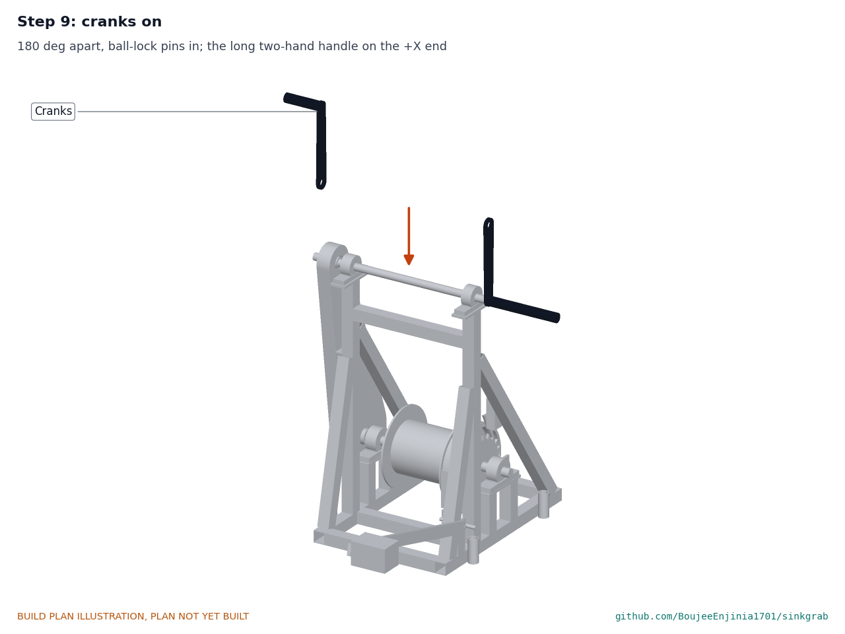
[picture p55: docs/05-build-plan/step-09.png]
Step 9


Slide each crank onto its square, 180 degrees apart, and push in the ball-lock pin. The crank with the long two-hand handle goes on the +X end, away from the chain guard; during the hoist two people work it and one the other crank.

### Step 10: crosshead and hinge pin into the shells

Step 10

Lay the shells lip to lip. Fit the sheave between the crosshead plates on its axle, set the crosshead between the shells and push the hinge pin through all end plates and both crosshead plates; R-clips.

### Step 11: tie rods onto the shell lugs

Step 11

Pin two tie rods to each shell's lugs, outside that shell's end plates.

### Step 12: head onto the tie rods

Step 12

Lift the head over the rods and pass the head pins through their upper holes; R-clips. The grab now opens when the head is pushed down and closes when the crosshead is lifted toward it.

### Step 13: ballast plates, upper sheave and shear link

Step 13

Bolt both ballast plates on with M10 bolts. Fit the upper sheave between the head's cheeks on its axle; R-clips. Pin the shear link to the crosshead's dead-end lug and fit a calibrated link pin. The assembled grab weighs about 51 kg; two people lift it.

### Step 14: arms, struts and sleeve onto the pole

Step 14

Slide the sleeve onto the pole from the spike end, slots facing the cross hole. Push the cross pin through one slot, the pole and the other slot, and fit its R-clip. Pin the arms to the hub lugs and the struts between the arms and the sleeve lugs.

### Step 15: pole section and T-bar

Step 15

Push a section's spigot into the scraper head and bolt it; fit the T-bar socket over the top spigot. At the well, sections are added one at a time at the doors.

### Step 16: well-head frame on the collar

Step 16

Clear and level the collar top. Set the two frame halves on it, bolt the corners and turn the frame so its datum holes lie over the caisson ring wall.

### Step 17: hang the doors

Step 17

Drop each door's hinge pins into the knuckles and close both. The doors stay closed whenever nothing is passing through.

### Step 18: cradle under the leg A foot

Step 18

With the HatchSide tripod standing over the well and its winch removed, lift the leg A foot a few centimetres, slide the cradle under it with the sheave pointing away from the well, lower the foot inside the rim and bolt the two clamp bars down.

### Step 19: capstan and drawbar

Step 19

Carry the capstan frame and the drum separately and reassemble them (steps 2, 4 to 9). Set the capstan in line with leg A, 3 m beyond the sheave. Join the drawbar halves and pin it to both clevises; drive the four stakes.

### Step 20: reeve the line and hang the grab

Step 20

Fit the 8 mm head sheave in the HatchSide head. Clamp the line on the drum, wind on three dead turns, lead it under the lead sheave, up beside leg A, over the head sheave and down the well axis. Thread it down through the grab head's guide, under the crosshead sheave, up over the upper sheave in the head and down to the shear link on the crosshead; shackle the thimble on the link pin. Tie the recovery line to the head's eye and make it off at the frame.

## 5. First checks

These are listed here and recorded in a TRL 4 test report, not in this plan.

*Table 2. First checks.*

| Check | Requirement | How | Pass when |
| --- | --- | --- | --- |
| Fit in rings | R2 | Pass the closed grab and the folded scraper through rings of 0.8, 1.0 and 1.3 m on the ground | Nothing binds; the arms open below the ring edge |
| Proof load | R7 | CalRig or a load cell, held 1 min: line, tripod, cradle and capstan to 193 kg (1.89 kN) | No movement over 2 mm, no damage |
| Shear link release | R7 | Pull the dead end through a load cell | Releases between 1.20 and 1.47 kN; the grab opens |
| Crank pin release | R7 | Hold the grab against a fixed stop, crank slowly | Pin shears below 2.2 kN on the innermost layer; the pawl holds |
| Brake | R7 | Lower the full grab on the brake, let go of the lever | The drum stops within one turn |
| Crank force | R5 | Spring balance on a handle, full grab | 150 N or less per person |
| Bite | R3 | Test pit of saturated sand, 20 bites into a measured tub | Record the mean bite |
| Cycle time | R4 | 20 cycles at 10 m, three people at the cranks during the hoist (two otherwise); then 20 with two | 3 min or less a cycle with three at the hoist; record both |
| Sinking and tilt | R1, R6 | Partner well; dip tape every cycle | Record depth gained and tilt |
| Mass and packing | R9 | Weigh each piece, the scraper head with its arms unpinned; load the kit | Each 25 kg or less; record the vehicle used |

## 6. Safety stops

Work stops at each of these points until what is listed is true.

1. **Before anything is lifted over the well.** The barrier stands 2 m outside the tripod feet. The shaft air has been tested with the gas detector. The chain guard is on and the brake weight is fitted. Everyone has been briefed with the card: one signaller, whistle and hand signals; one blast stops all work.
2. **Before the first lift on a site.** The line, cradle, drawbar, capstan and tripod have been proof-loaded for 1 min at 193 kg with nobody near the well. The rope, splice, shackles and pins have been inspected that day. The link pin is a calibrated pin from the tested coil; the crank pin is a 3 mm mild steel pin.
3. **Before each lift.** Nobody is under the grab, beside the line or on the doors. The doors are open only while the grab passes.
4. **Before lowering.** The cranks are off and the pawl is up; the person on the brake has both hands on the lever. During the hoist three people work the cranks; on the stop call all three let go together, the pawl holds the drum, and nobody stands between the capstan and the lead sheave.
5. **Before dumping.** The doors are closed under the grab and the tub is in place; nobody reaches under the grab.
6. **After a shear link or crank pin breaks.** Stop, slack the line, find the snag, and recover the grab on the recovery line if it is on the bottom. Fit a new pin of the specified kind only.
7. **When tilt passes 1 in 160.** Scrape only the high side and move saddles to it. At 1 in 80, stop all undercutting until it is back under 1 in 160.
8. **If anyone must look into or enter the shaft.** SinkGrab work stops. Entry is a separate operation: gas test, harness on a separate line with rescue equipment, a person at the top throughout. SinkGrab's line is never used for a person.
9. **At the end of each day.** Close the doors, inspect the rope, pins, pawl, brake lining and shackles, and replace anything damaged.

## 7. Tools, skills and workspace

- Stick welder with 2.5 mm electrodes or MIG, and a person who can weld 2 mm tube without burning through; welding screen, gloves and mask.
- Angle grinder with cutting and grinding discs; metal saw; pillar drill with bits to 30 mm.
- Plate rolls for the shell skins, or a fabricator who has them; a profile cutter for the ratchet, pawl and end plates.
- Spanners to M14, R-clip pliers, a splicing fid if the eye splices are made in house.
- A flat floor or welding table about 1.5 x 1.5 m; two people for the drum, frames and grab.
- At the well: the HatchSide tripod and its crew of two; a crew of four or five in all.

## 8. Where the numbers come from

- `cad/src/model.py`: the parametric model, its constructability checks and the STEP and STL files in `cad/step` and `cad/stl`.
- `cad/drawings/SKG-DWG-001` and `SKG-DWG-002`: the well-head layout and the grab and scraper general arrangement; `SKG-DWG-101` to `SKG-DWG-117`: making sketches.
- `docs/04-calcs/01-sizing.md` and `docs/04-calcs/sizing.py` (SKG-CAL-001): loads, limits, forces, masses and cost.
- `bom/bom.csv`: parts, specifications and prices.
- `docs/decisions/0002-design-for-construction.md` (SKG-DDR-002): the changes in section 2; `docs/decisions/0003-round-2-requirement-decisions.md` (SKG-DDR-003): the third person at the cranks, the 3:1 tackle and the toe blades.
- `cad/src/build_plan_media.py`: every picture in this plan.

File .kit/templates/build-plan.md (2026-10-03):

---
doc_id: PRJ-BLD-001
title: Project prototype build plan
project: Project name
doc_type: Build plan
version: "0.1"
status: Draft
date: YYYY-MM-DD
author: Amish Chadha
license: CERN-OHL-S-2.0
revisions:
  - version: "0.1"
    date: YYYY-MM-DD
    author: Amish Chadha
    change: First build plan; design made constructable
---

# Project prototype build plan

**Plan, not yet built.** How to build the first proof-of-concept prototype, component by component. Building and testing to it is TRL 4 work. Decisions still to be made are kept in the design decisions register (`docs/06-design-decisions.md`), not here.

## 1. What you are building

Every component, pulled apart and numbered in build order

One short paragraph: what the prototype is, how many components, which are made and which are bought, and the main ways they are made.

## 2. What changed to make it buildable

| Component | The concept had | The buildable design has | Why |
| --- | --- | --- | --- |

## 3. Making the components

### 3.1 Component name

Making sketch

**What it is and what it is made from.**

**How to make it.**

1. Mark out ...
2. Cut ...

**How it fits the parts next to it.**

Close-up of the joint

**Check before moving on.**

## 4. Putting it together

### Step 1: ...

Step 1

## 5. First checks

| Check | Requirement | How | Pass when |
| --- | --- | --- | --- |

## 6. Safety stops

## 7. Tools, skills and workspace

## 8. Where the numbers come from

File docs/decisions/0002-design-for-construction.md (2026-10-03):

---
doc_id: SKG-DDR-002
title: SinkGrab design for construction
project: SinkGrab
doc_type: Design decision record
version: "0.1"
status: Draft
date: '2026-10-03'
author: Amish Chadha
license: CERN-OHL-S-2.0
revisions:
- version: "0.1"
  date: '2026-10-03'
  author: Amish Chadha
  change: Constructability review and changes that make the design buildable, decided under Amish's pre-approvals of 2026-10-03
---

# 0002: Design for construction

- **Date:** 2026-10-03
- **Status:** accepted

## Context

STANDARDS section 18 asks for every part to be makeable by its stated process and to fit and fasten to its neighbours (Amish, 2026-09-30: "fix the design assumptions to match and be physically feasible"). The TRL 2 concept (SKG-PRC-001 v0.2, SKG-DDR-001) was modelled part by part in `cad/src/model.py`: how each part is made, how it joins each neighbour, and build123d checks for overlapping parts, for parts that do not touch what holds them, and for the folded scraper passing the smallest ring. The checks now report no overlaps and no floating parts. Amish pre-approved every recommendation on 2026-10-03 ("start with the first 14 repos from the list of 29 projects. I pre-approve the batch runs along with any recommendations you come up with. I also accept any cost overruns or variations from the assumed scope cost.") and extended it the same day to this batch ("Proceed with the remaining 15 scaffolds"). No change alters what SinkGrab does or its pitch; the safety-related changes all take the conservative side.

## Options considered

For each problem the simplest physically sound fix was chosen; alternatives are noted in Table 1.

## Decision

*Table 1. Changes made for construction.*

| # | Part | Problem found | Change | Why |
| --- | --- | --- | --- | --- |
| 1 | Capstan position | A 69 kg capstan cannot hang on the tripod's aluminium leg | Ground capstan 3.0 m from a lead sheave; drawbar of two 48.3 mm halves to a cradle under the leg A foot | Fleet angle 1.9 degrees; the pull closes inside the kit |
| 2 | Head sheave | The HatchSide sheave is grooved for 6 mm wire | A bought 150 mm sheave grooved for 8 mm fibre rope fits the same cheeks and axle | Groove fit; 16 rope diameters |
| 3 | Capstan frame | First model 32 kg in 40 x 40 x 2.6 tube with a solid anchor bar | 40 x 40 x 2 tube, 8 mm pads, anchor bar as tube: 22.9 kg | R9 |
| 4 | Drum | 8 mm solid flanges and webs | 6 mm flanges and brake web with lightening holes: 18.3 kg | R9 |
| 5 | Pawl | A pawl pivoted ahead of the nose ran its body through the tooth tips | Pivot 150 mm from the axis at 75 degrees, behind the nose; bracket hung from the front brace | Clears the teeth; holds the paying-out direction |
| 6 | Brake | Not detailed | Lined band 270 degrees round a 250 mm brake drum; anchor post, link, 650 mm lever with a 6 kg weight; anchor and link moved apart so they cannot touch | Brake on when let go; 314 N m |
| 7 | Stakes and guard | Stake heads clashed with the braces; guard tabs inside the guard wall | Stake tubes 200 mm either side of the axis; frame tabs reach the guard face | Fit |
| 8 | Grab mass | First model 72 kg, too close to the link release with a full bite | 4 mm skin, 6 mm end plates, 4 mm top cover, hollow 6 mm head box, 30 x 10 tie rods: 47.9 kg | Link margin 1.19 |
| 9 | Grab hinge | Both shells' end plates in one plane at the pin | Shell B's end plates outside shell A's; each shell's tie rods outside its own end plates; short pins at the lugs | Interleaved hinge, no clash |
| 10 | Shear link | Not detailed | Two 6 mm plates on a 16 mm pin through the dead-end lug; calibrated pin of about 1.9 mm below | R7; opens the grab if it snags |
| 11 | Scraper arms | Arms fixed open would not pass the bore | Arms pinned to the hub, opened by struts from a sliding sleeve and foot; a 300 mm lift folds the toes to 364 mm radius | R2 |
| 12 | Scraper pole | Pole sections were not defined | 42.4 x 2.6 tube in 2.0 m sections with 36 mm spigots and M12 cross bolts; T-bar socket and eye | R9 (fits a small pickup) |
| 13 | Spoil and cover | A chute over the mouth could not also cover the shaft | Well-head frame in two halves on the collar with two mesh doors, a 64 mm pole hole and four datum brackets | Covers the shaft; pole guide; tilt datum |
| 14 | Ballast | A frame on the top ring needed placing by hand | Eight 20.6 kg U-saddles straddling the ring wall, each on a 6 mm line | Placed from the surface |
| 15 | Clearances | Pins in 1 mm oversize holes left parts unconnected in the checks | Holes 0.25 to 0.5 mm over the pin | Each part rests on what holds it |

## Consequences

- `cad/src/model.py` holds the constructable design; STEP and STL, SKG-DWG-001 and 002 (Rev P2), the concept media and the build plan pictures are generated from it.
- SKG-CAL-001 is run on it; the parts cost is USD 2,506, USD 1,494 under the value-engineering target.
- `design_state: constructable` is set in `project.yaml`.

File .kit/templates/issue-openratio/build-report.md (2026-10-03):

---
name: Build report
about: Tell us what happened when you built, printed or tested part of this design
title: "Build report: "
labels: build-report
---

This is a research and educational prototype, not a medical device. It is a TRL 3 concept and is not released for fabrication. If you build any part of it, you do so at your own risk. Reports help everyone.

**What you built** (part, sub-assembly or test)

**Materials, tools and settings**

**What worked**

**What did not work, with photos or measurements if you have them**

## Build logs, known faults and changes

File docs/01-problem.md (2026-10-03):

---
doc_id: SKG-PRB-001
title: SinkGrab problem statement
project: SinkGrab
doc_type: Problem statement
version: "0.2"
status: Draft
date: '2026-10-03'
author: Amish Chadha
license: CERN-OHL-S-2.0
revisions:
- version: "0.1"
  date: '2026-09-30'
  author: Amish Chadha
  change: Initial scaffold
- version: "0.2"
  date: '2026-10-03'
  author: Amish Chadha
  change: TRL 2 update; first co-design candidate, safety section, open questions answered by the TRL 2 review (SKG-DDR-001) and replaced by questions for the first trials
---

# SinkGrab problem statement

A hand-dug well is only as reliable as its depth below the dry-season water table. Crews stop near the water table because digging further means pumping the well dry or working under water, and both are costly and dangerous.

## The problem

Standard practice for lined wells is to dig below the water table inside smaller precast caisson rings that sink as soil is removed from under them ([WaterAid technical brief](https://sswm.info/sites/default/files/reference_attachments/WATERAID%202013.%20Hand-dug%20wells.pdf)). The target is a minimum of 2 to 3 m of water depth ([Abbott, Hand Dug Wells manual](https://sswm.info/sites/default/files/reference_attachments/ABBOT%204000%20Hand%20Dug%20Well%20Manual.pdf)). Without de-watering pumps the limit of penetration is only about 1 m ([Akvopedia](https://akvopedia.org/wiki/Traditional_hand-dug_wells)), so the dry season finds the intake too shallow. The manual also warns that one of the greatest challenges in caisson sinking is keeping the bottom ring from falling out of line, with one side going ahead of the other ([Abbott](https://sswm.info/sites/default/files/reference_attachments/ABBOT%204000%20Hand%20Dug%20Well%20Manual.pdf)).

Existing methods all put a person at the bottom. The manual method is a short hoe and buckets inside the ring, with electric or compressor-driven pumps to keep the water down ([Abbott](https://sswm.info/sites/default/files/reference_attachments/ABBOT%204000%20Hand%20Dug%20Well%20Manual.pdf)); Oxfam's rehabilitation method is to bail the well with buckets and then excavate by hand ([Oxfam WASH](https://www.oxfamwash.org/repairing-cleaning-and-disinfecting-hand-dug-wells/)). Large bridge-foundation wells are sunk without anyone inside by dredging with a plate grab from a crane, and tilt is corrected by eccentric grabbing and loading ([Construction Civil](https://www.constructioncivil.com/well-sinking-tilt-shift-in-well-foundation/)). That principle works, but the equipment is crane-scale. Nothing open exists at the scale of a 1 m village well, worked by two or three people from a tripod.

## Users and context

| User | Need | Context |
| --- | --- | --- |
| Village well-digging crews | Dig 2 to 3 m below the water table without pumps or anyone under water | Dry-season deepening and new caisson wells, crews of 3 to 5 |
| WASH programme engineers (NGOs, district water departments) | A documented, repeatable method they can specify, train and inspect | Well rehabilitation programmes and drought response |
| Well committees and households | A well that gives water all year at a cost they can meet | Community and household wells, often shared |
| Local fabricators | Drawings they can build and repair with a welder, drill and hand tools | Small workshops near the well sites |

## Operating environment

- Hand-dug wells about 0.8 to 1.5 m internal diameter (estimate of the common range), lined with precast concrete or brick rings, with smaller caisson rings below the water table.
- Well depth about 5 to 30 m (estimate); water standing 0 to 3 m over the digging face.
- Soils from silt and fine sand to laterite, clay and gravel; boulders possible. Fine sand can boil up into the ring.
- Hot, dusty or wet surroundings; no mains power; work often in the dry season when water tables are lowest.
- Possible foul air in the shaft (carbon monoxide, carbon dioxide or hydrogen sulphide).

## Constraints

- Value-engineering target of USD 4,000 for the full kit, excluding the HatchSide tripod (a hypothetical control target, not a spending limit).
- No motor pump in or at the well during digging; human-powered only (hand capstan).
- No one in the well while the grab or scraper is working.
- Every piece carried by one or two people; total kit fits in a small pickup (target).
- Built from common steel section, rope and fasteners with hand tools and a stick welder.
- Hardware under CERN-OHL-S-2.0; any software or calculation scripts under MIT.

## Out of scope

- Drilled boreholes and machine-dug wells.
- Suction or jet dredging (sand dredger methods).
- Well lining design and ring casting (uses existing precast rings).
- Water quality treatment and handpump selection.
- Rescue from wells; HatchSide covers entry-free retrieval separately.

## Prior work

| Prior work | What it does | Gap for these users | Source |
| --- | --- | --- | --- |
| Abbott, Hand Dug Wells: Choice of Technology and Construction Manual | Field manual for caisson wells: dig with a short hoe inside the ring, sink rings 2 to 3 m below the water table, de-water with electric or compressor pumps | Needs a person at the bottom and a pump; does not cover digging from the surface | [link](https://sswm.info/sites/default/files/reference_attachments/ABBOT%204000%20Hand%20Dug%20Well%20Manual.pdf) |
| WaterAid technology brief, hand-dug wells | Excavation below the water table inside smaller precast caisson rings, with de-watering | Assumes de-watering to keep excavating | [link](https://sswm.info/sites/default/files/reference_attachments/WATERAID%202013.%20Hand-dug%20wells.pdf) |
| Oxfam, repairing, cleaning and disinfecting hand-dug wells | Bail with buckets, then excavate debris by hand; never lower a petrol or diesel pump into a well | Manual excavation at the bottom; slow bailing limits depth gained | [link](https://www.oxfamwash.org/repairing-cleaning-and-disinfecting-hand-dug-wells/) |
| Well foundation sinking with plate grab | Bridge-foundation wells sunk by grabbing soil under water, with eccentric grabbing and kentledge to correct tilt | Crane-scale plant for multi-metre wells; not usable at a 1 m village well | [link](https://www.constructioncivil.com/well-sinking-tilt-shift-in-well-foundation/) |
| CN101787703B, sinking well construction in saturated gravel (China 22MCC Group) | Open-caisson sinking in saturated gravel and pebble beds using a sand dredger moved around the well; active, anticipated expiry 2030 | Machine dredger method; SinkGrab uses a rope grab and scraper, not a dredger | [link](https://patents.google.com/patent/CN101787703B/en) |
| US1750728A, well-tool grab (expired) | Four-arm grab worked from the well mouth to retrieve lost tools | Fishing tool for lost equipment, not a soil grab | [link](https://patents.google.com/patent/US1750728) |

## Co-design

The design is meant to be tested in real wells with the crews who will use it. The first candidate to approach is the Kerala Ground Water Department through one of its district offices, with a village well-digging crew it already works with; a rural water NGO in the Ethiopian highlands is the second (SKG-DDR-001, item 12). Neither has been approached or has agreed.

## Safety

> **Safety:** Deepening a well is lifting work over an open shaft. People can fall into the well, be struck by a falling tool or a dropped load, be overcome by bad air in the shaft, or be caught when a lining ring drops suddenly. SinkGrab exists so that nobody works at the bottom; every part of the method keeps people at the surface, behind a barrier, with the shaft covered whenever the grab is up. It is an open engineering reference, not certified lifting or well-construction equipment.

## Questions for the first trials

The TRL 2 review answered the scaffold's open questions on paper (SKG-DDR-001): a two-shell clamshell rather than an orange peel; a centred pole and centralizer to guide the scraper; no de-watering, so the water inside the rings stays level with the water outside and the sand has no upward gradient to boil; tilt checked every cycle with a stop at 1 in 80; and the patent search for under-curb scraper claims before release. What only a trial can settle:

- How full the grab comes up in saturated fine sand, laterite and clayey sand (SKG-CAL-001 assumes 75 %).
- Whether the rings keep sinking to 3 m below the water table, and the skin friction that sets it (SKG-CAL-001 shows the limit is about 1.7 kPa).
- How evenly the scraper undercuts, and whether scraping the high side alone corrects tilt.
- The real cycle time at 10 m with two and with three people at the cranks.

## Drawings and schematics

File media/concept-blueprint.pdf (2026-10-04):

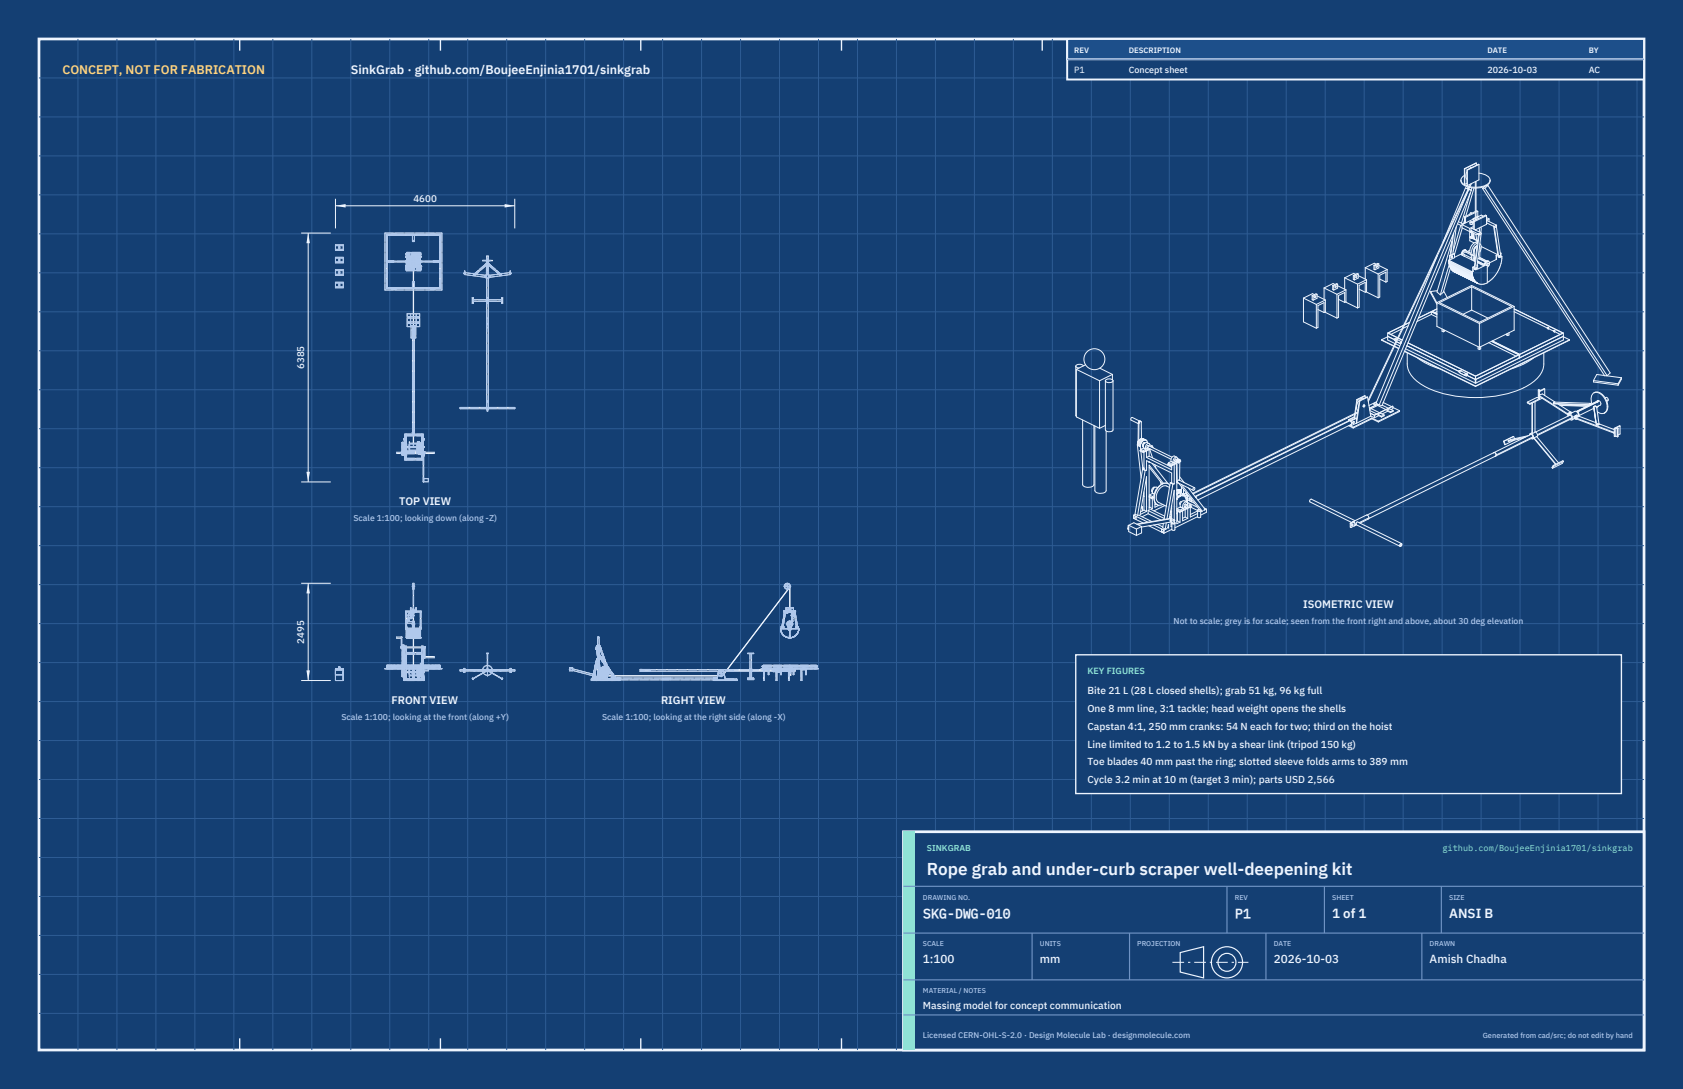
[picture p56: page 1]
CONCEPT, NOT FOR FABRICATION; SinkGrab · github.com/BoujeeEnjinia1701/sinkgrab; FRONT VIEW; TOP VIEW; RIGHT VIEW; ISOMETRIC VIEW; REV; DESCRIPTION; DATE; Concept sheet; SINKGRAB; github.com/BoujeeEnjinia1701/sinkgrab; DRAWING NO. SKG-DWG-010; REV P1; SHEET 1 of 1; SIZE ANSI B; SCALE 1:100; UNITS mm; PROJECTION; DRAWN Amish Chadha; Licensed CERN-OHL-S-2.0 · Design Molecule Lab · designmolecule.com; Generated from cad/src; do not edit by hand

Scale 1:100; looking down (along -Z)

Not to scale; grey is for scale; seen from the front right and above, about 30 deg elevation

KEY FIGURES
Bite 21 L (28 L closed shells); grab 51 kg, 96 kg full
One 8 mm line, 3:1 tackle; head weight opens the shells
Capstan 4:1, 250 mm cranks: 54 N each for two; third on the hoist
Line limited to 1.2 to 1.5 kN by a shear link (tripod 150 kg)
Toe blades 40 mm past the ring; slotted sleeve folds arms to 389 mm
Cycle 3.2 min at 10 m (target 3 min); parts USD 2,566

Scale 1:100; looking at the front (along +Y)

Scale 1:100; looking at the right side (along -X)

Rope grab and under-curb scraper well-deepening kit

MATERIAL / NOTES
Massing model for concept communication

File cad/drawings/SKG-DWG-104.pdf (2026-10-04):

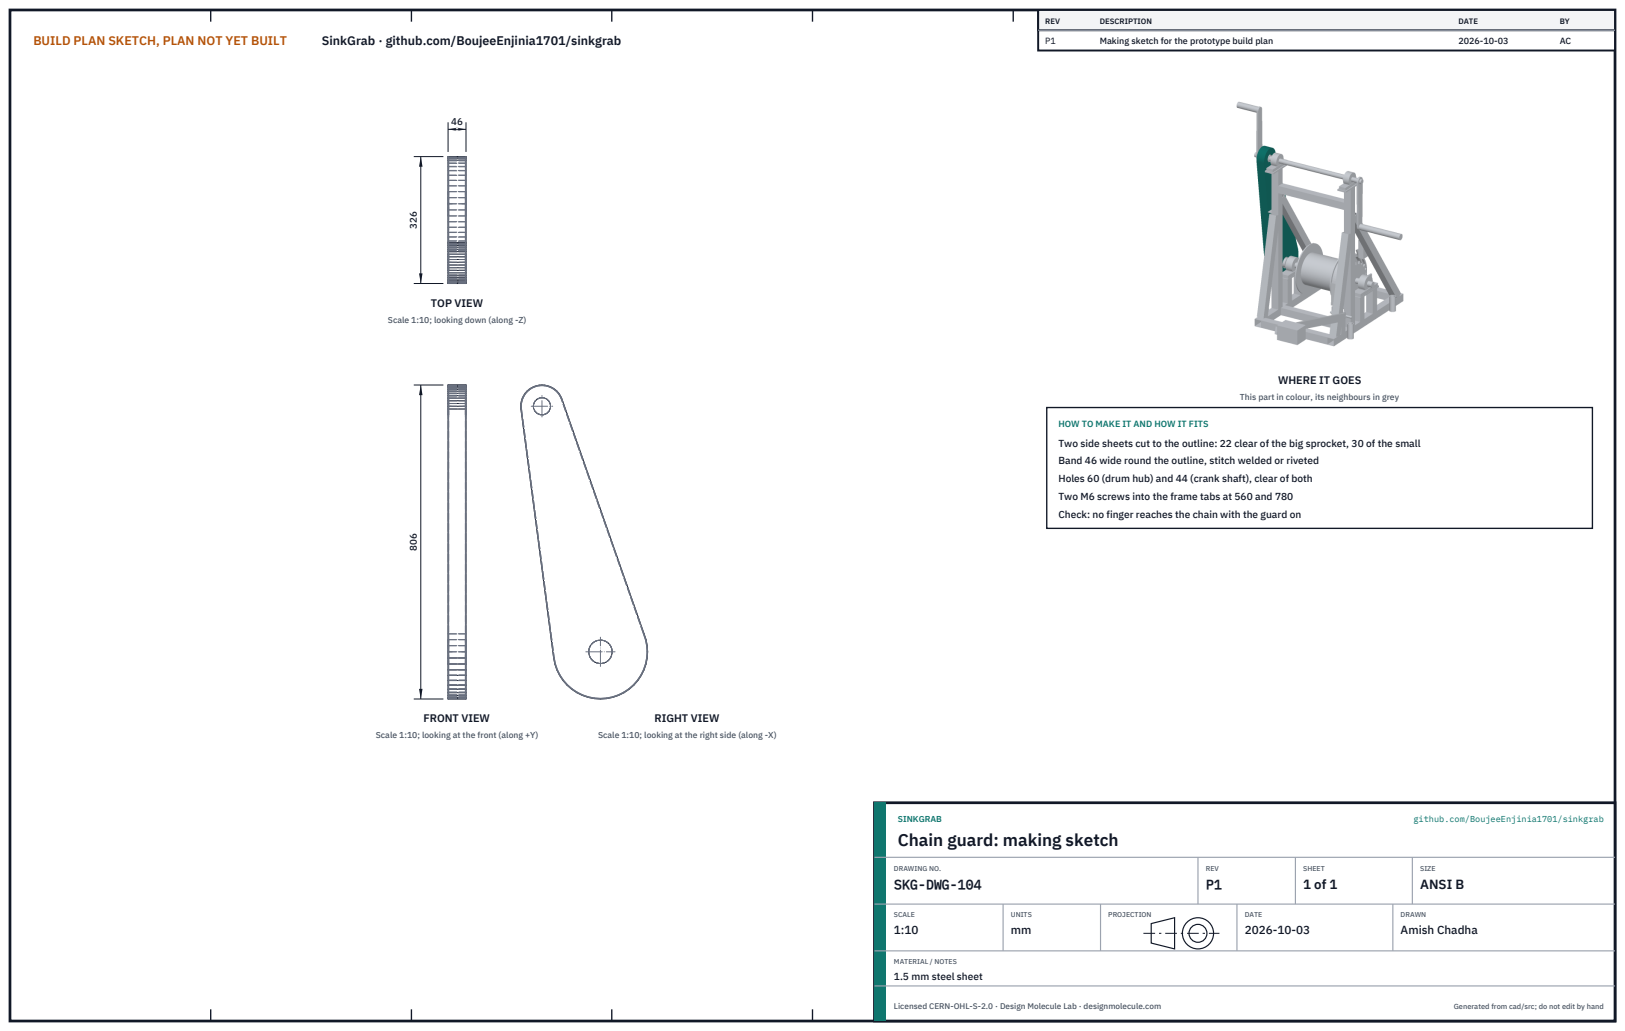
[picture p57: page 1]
BUILD PLAN SKETCH, PLAN NOT YET BUILT; SinkGrab · github.com/BoujeeEnjinia1701/sinkgrab; FRONT VIEW; TOP VIEW; RIGHT VIEW; REV; DESCRIPTION; DATE; Making sketch for the prototype build plan; SINKGRAB; github.com/BoujeeEnjinia1701/sinkgrab; DRAWING NO. SKG-DWG-104; REV P1; SHEET 1 of 1; SIZE ANSI B; SCALE 1:10; UNITS mm; PROJECTION; DRAWN Amish Chadha; Licensed CERN-OHL-S-2.0 · Design Molecule Lab · designmolecule.com; Generated from cad/src; do not edit by hand

Scale 1:10; looking down (along -Z)

WHERE IT GOES

This part in colour, its neighbours in grey

HOW TO MAKE IT AND HOW IT FITS
Two side sheets cut to the outline: 22 clear of the big sprocket, 30 of the small
Band 46 wide round the outline, stitch welded or riveted
Holes 60 (drum hub) and 44 (crank shaft), clear of both
Two M6 screws into the frame tabs at 560 and 780
Check: no finger reaches the chain with the guard on

Scale 1:10; looking at the front (along +Y)

Scale 1:10; looking at the right side (along -X)

Chain guard: making sketch

MATERIAL / NOTES
1.5 mm steel sheet

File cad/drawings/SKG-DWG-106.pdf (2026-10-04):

## BUILD PLAN SKETCH, PLAN NOT YET BUILT SinkGrab · github.com/BoujeeEnjinia1701/sinkgrab

### TOP VIEW

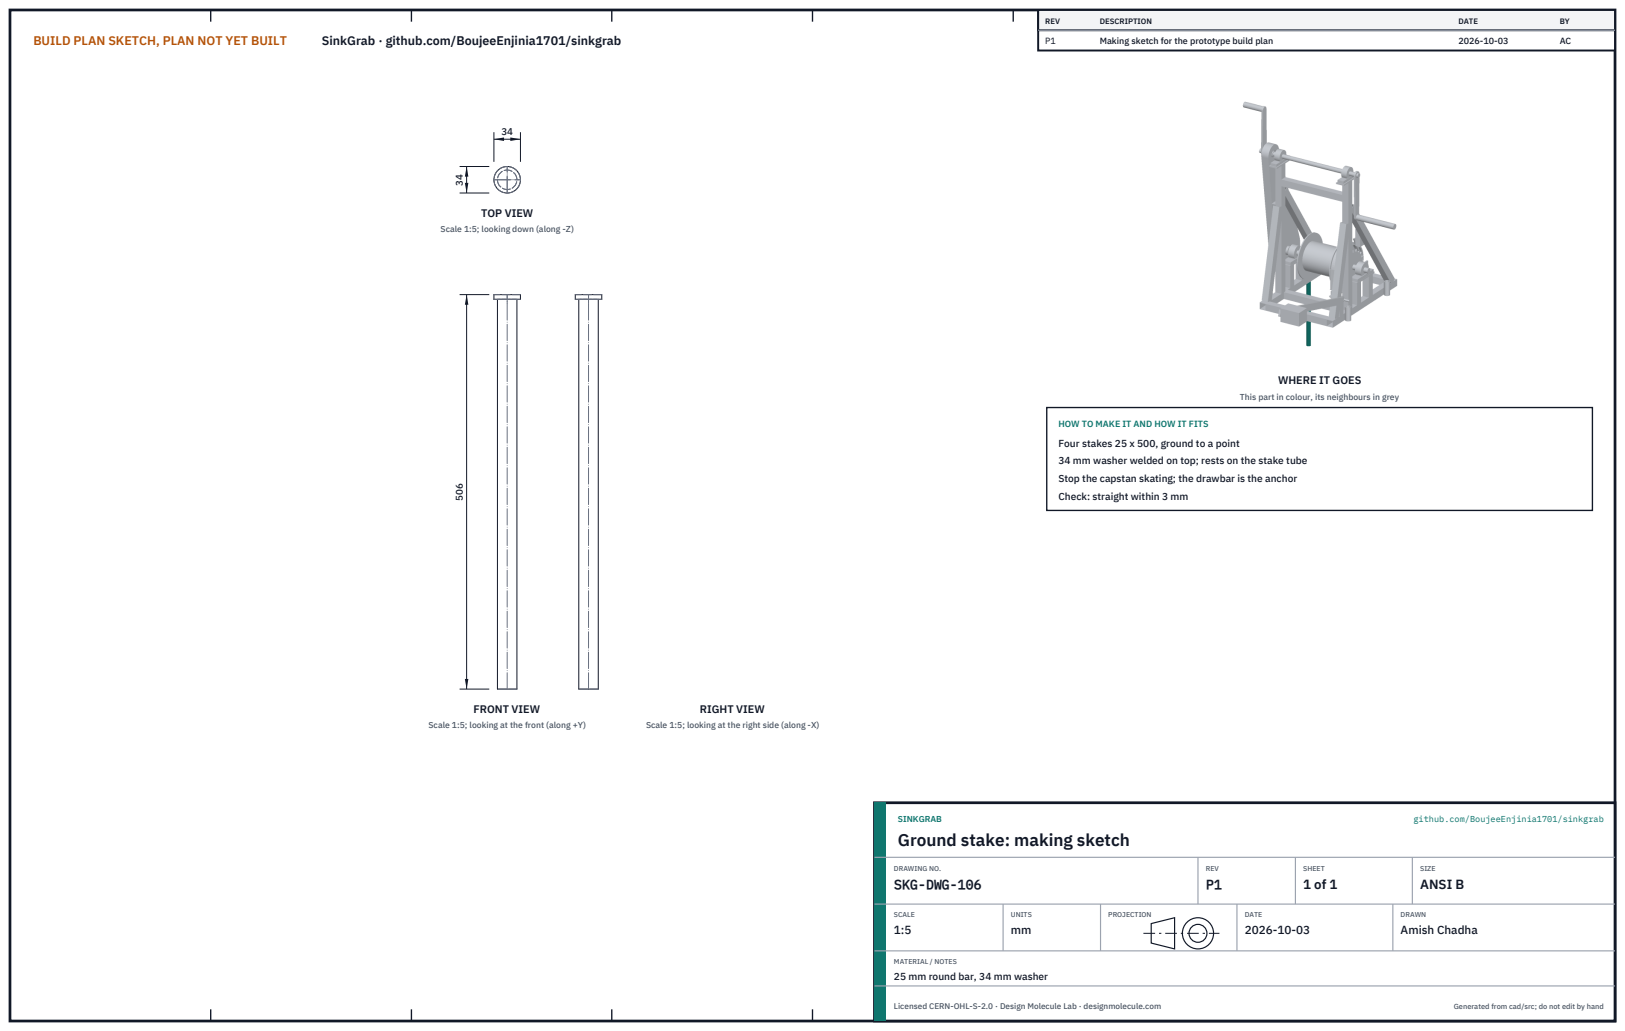
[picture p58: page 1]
FRONT VIEW; RIGHT VIEW; REV; DESCRIPTION; DATE; Making sketch for the prototype build plan; SINKGRAB; github.com/BoujeeEnjinia1701/sinkgrab; DRAWING NO. SKG-DWG-106; REV P1; SHEET 1 of 1; SIZE ANSI B; SCALE 1:5; UNITS mm; PROJECTION; DRAWN Amish Chadha; Licensed CERN-OHL-S-2.0 · Design Molecule Lab · designmolecule.com; Generated from cad/src; do not edit by hand

Scale 1:5; looking down (along -Z)

WHERE IT GOES

This part in colour, its neighbours in grey

HOW TO MAKE IT AND HOW IT FITS
Four stakes 25 x 500, ground to a point
34 mm washer welded on top; rests on the stake tube
Stop the capstan skating; the drawbar is the anchor
Check: straight within 3 mm

Scale 1:5; looking at the front (along +Y)

Scale 1:5; looking at the right side (along -X)

Ground stake: making sketch

MATERIAL / NOTES
25 mm round bar, 34 mm washer

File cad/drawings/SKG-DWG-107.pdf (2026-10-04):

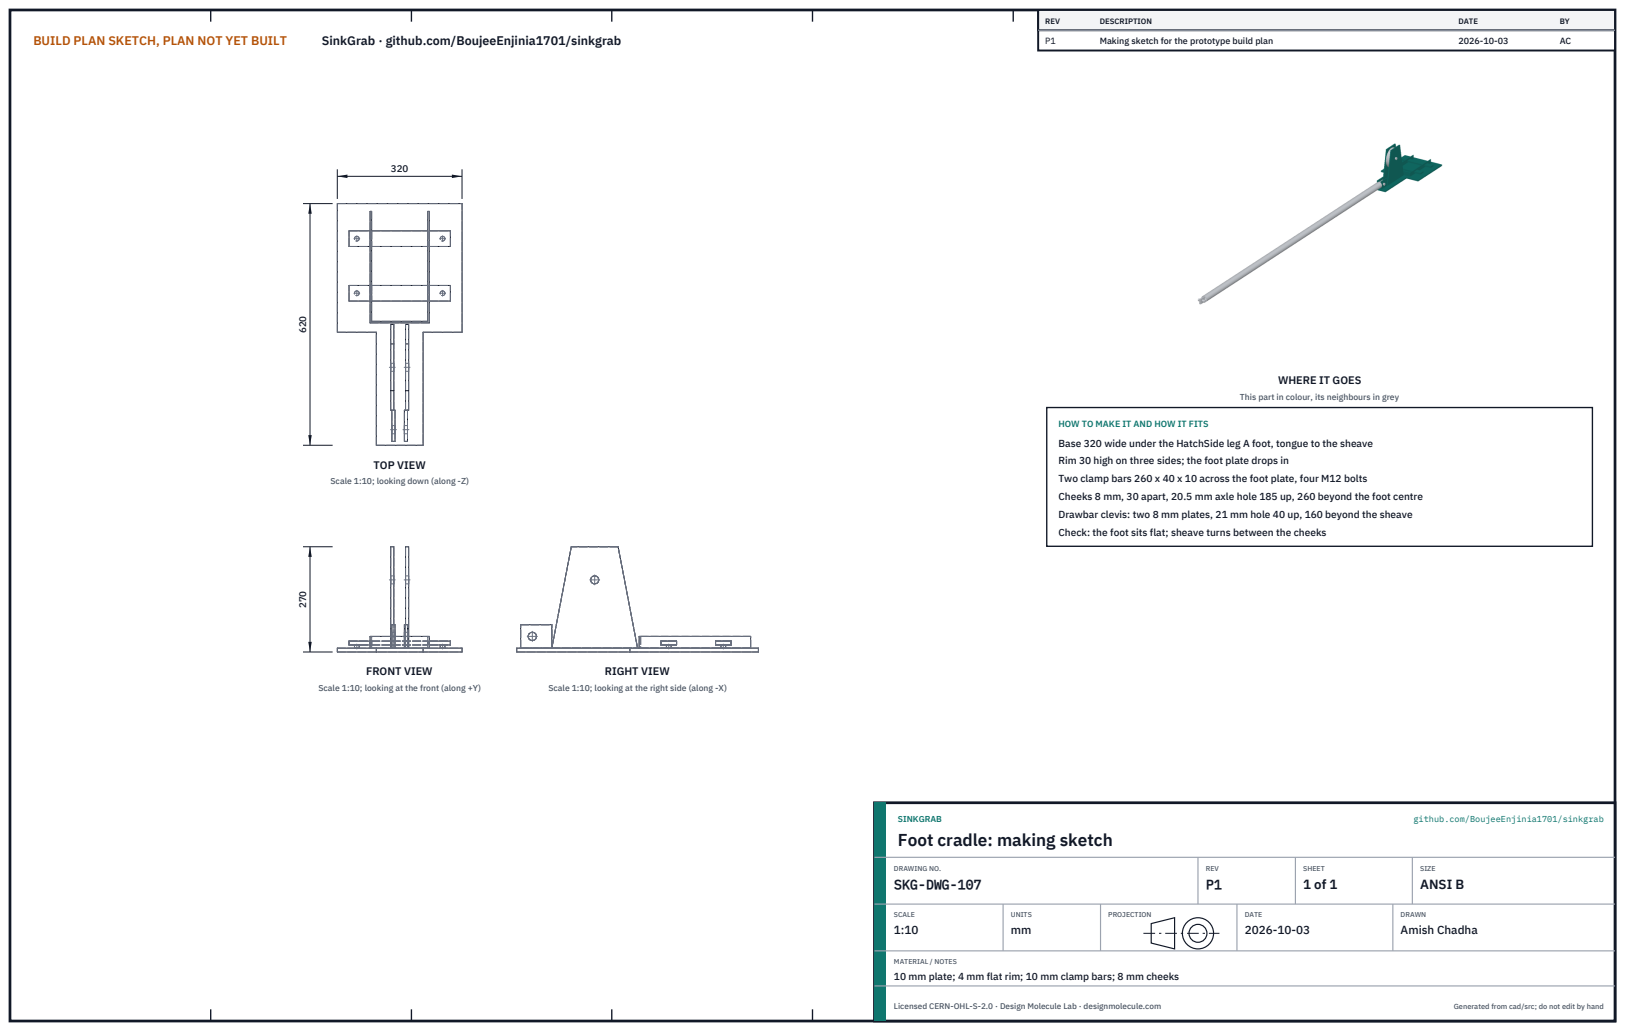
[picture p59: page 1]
BUILD PLAN SKETCH, PLAN NOT YET BUILT; SinkGrab · github.com/BoujeeEnjinia1701/sinkgrab; FRONT VIEW; TOP VIEW; RIGHT VIEW; REV; DESCRIPTION; DATE; Making sketch for the prototype build plan; SINKGRAB; github.com/BoujeeEnjinia1701/sinkgrab; DRAWING NO. SKG-DWG-107; REV P1; SHEET 1 of 1; SIZE ANSI B; SCALE 1:10; UNITS mm; PROJECTION; DRAWN Amish Chadha; Licensed CERN-OHL-S-2.0 · Design Molecule Lab · designmolecule.com; Generated from cad/src; do not edit by hand

WHERE IT GOES

This part in colour, its neighbours in grey

HOW TO MAKE IT AND HOW IT FITS
Base 320 wide under the HatchSide leg A foot, tongue to the sheave
Rim 30 high on three sides; the foot plate drops in
Two clamp bars 260 x 40 x 10 across the foot plate, four M12 bolts
Cheeks 8 mm, 30 apart, 20.5 mm axle hole 185 up, 260 beyond the foot centre
Drawbar clevis: two 8 mm plates, 21 mm hole 40 up, 160 beyond the sheave
Check: the foot sits flat; sheave turns between the cheeks

Scale 1:10; looking down (along -Z)

Scale 1:10; looking at the front (along +Y)

Scale 1:10; looking at the right side (along -X)

Foot cradle: making sketch

MATERIAL / NOTES
10 mm plate; 4 mm flat rim; 10 mm clamp bars; 8 mm cheeks

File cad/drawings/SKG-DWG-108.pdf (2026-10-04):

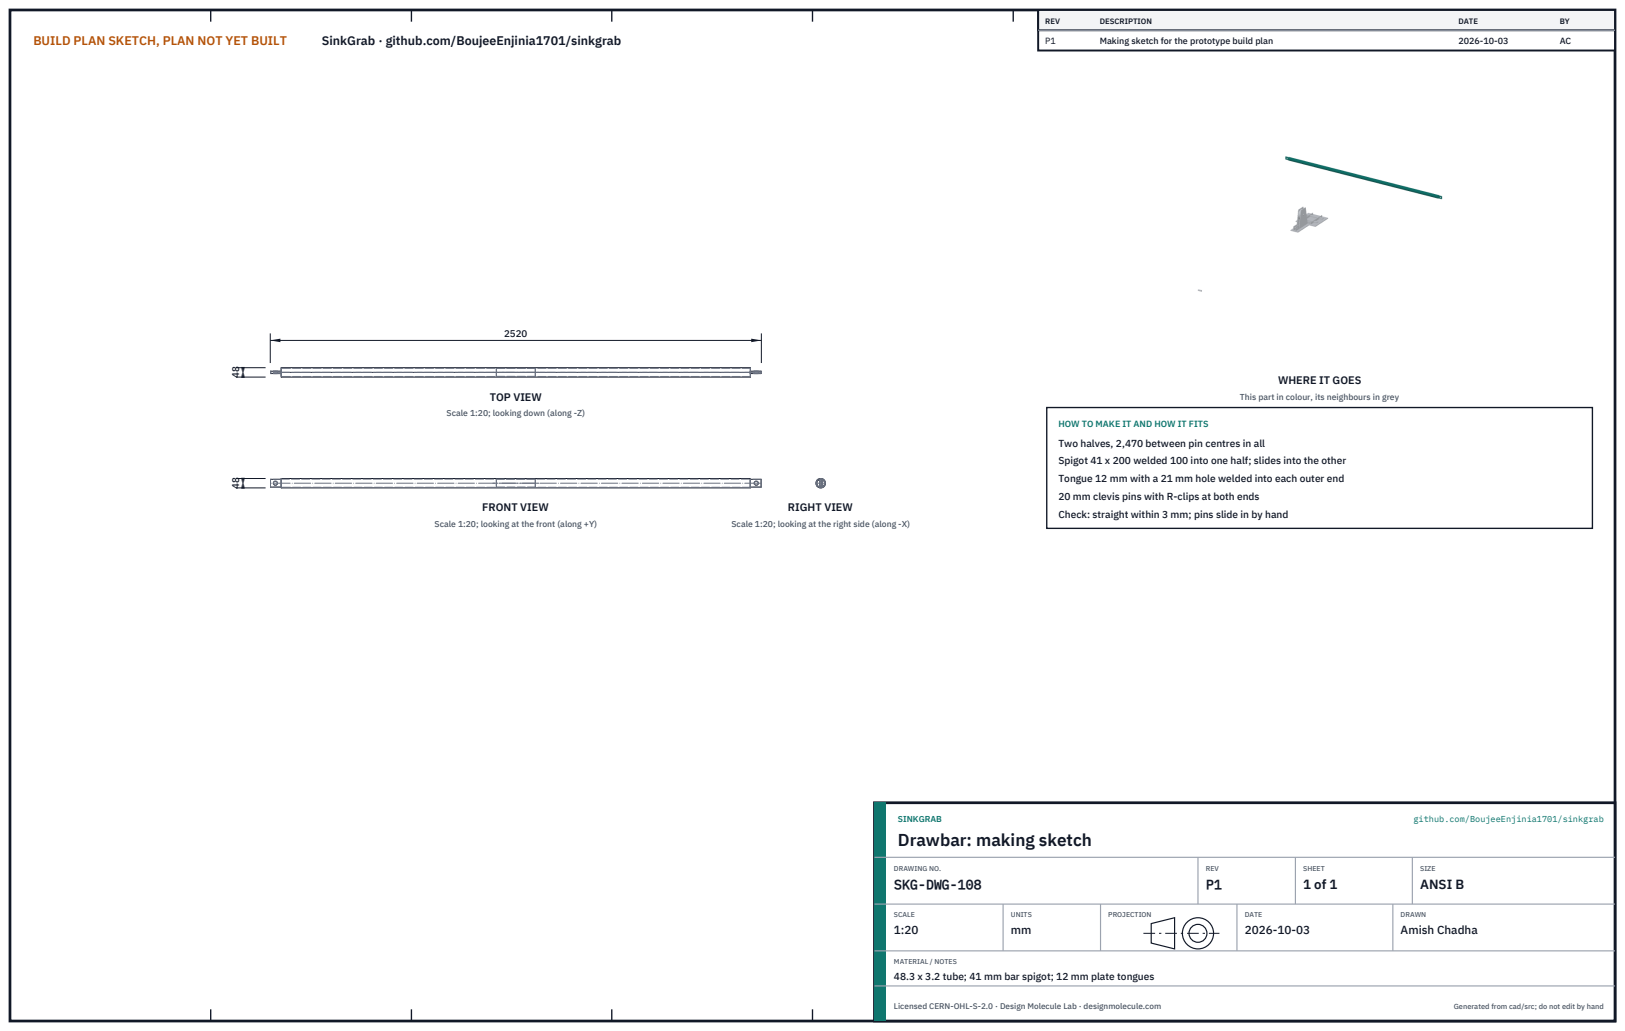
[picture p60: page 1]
BUILD PLAN SKETCH, PLAN NOT YET BUILT; SinkGrab · github.com/BoujeeEnjinia1701/sinkgrab; FRONT VIEW; TOP VIEW; RIGHT VIEW; REV; DESCRIPTION; DATE; Making sketch for the prototype build plan; SINKGRAB; github.com/BoujeeEnjinia1701/sinkgrab; DRAWING NO. SKG-DWG-108; REV P1; SHEET 1 of 1; SIZE ANSI B; SCALE 1:20; UNITS mm; PROJECTION; DRAWN Amish Chadha; Licensed CERN-OHL-S-2.0 · Design Molecule Lab · designmolecule.com; Generated from cad/src; do not edit by hand

WHERE IT GOES

This part in colour, its neighbours in grey

Scale 1:20; looking down (along -Z)

HOW TO MAKE IT AND HOW IT FITS
Two halves, 2,470 between pin centres in all
Spigot 41 x 200 welded 100 into one half; slides into the other
Tongue 12 mm with a 21 mm hole welded into each outer end
20 mm clevis pins with R-clips at both ends
Check: straight within 3 mm; pins slide in by hand

Scale 1:20; looking at the front (along +Y)

Scale 1:20; looking at the right side (along -X)

Drawbar: making sketch

MATERIAL / NOTES
48.3 x 3.2 tube; 41 mm bar spigot; 12 mm plate tongues

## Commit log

2026-10-03 SinkGrab at TRL 3: constructable design (kit 1.7.0)
    Problem, concept and requirements; sizing calculations; CAD model, STEP and STL; general arrangement drawing; bill of materials; build plan with making sketches, joint close-ups and step pictures; design decisions register (design choices decided under Amish's 2026-10-03 pre-approval; requirement decisions open for Amish); TRL 2 and TRL 3 review; photoreal renders and storefront card. Private until Amish opens it.
    [bom.csv, results.csv, sinkgrab-assembly.step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]
2026-10-04 Carry Amish's round 2 requirement decisions into the design
    Amish approved all 47 recommendations on 2026-10-03 ("i approve all of the 47 recommendations provided by you. Execute them."). Each repo gains a decision record (DDR-003, or the next free number for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
    [bom.csv, results.csv, sinkgrab-assembly.step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]
2026-10-04 Carry Amish's round-2 and round-3 decisions into the design
    Amish approved all 46 round-2 recommendations ("i agree with all the 46 recommendations you provided. please proceed.") and all round-3 recommendations ("For round 3, I agree with all your proposed r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
    [bom.csv, results.csv, sinkgrab-assembly.step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]
2026-10-28 Kit 1.9.1 upgrade: pipeline documents and detailed CAD for every option
    Kit 1.9.1 installed (.kit, CLAUDE.md, .claude/commands). Kit 1.8 pipeline: STEM check with fixes under the 2026-10-23 standing instruction, concept options with the current design as option A, URS, PRS, generated RTM, REG, FEA, RSK with design FMEA, MKT, PLN and DDR; kit 1.9 D3 model of every option passing cad/fidelity.json; independent review recorded in the STEM check. Amish's 2026-10-25 decisions recorded where he approved a recommendation; all others proposed, awaiting Amish. Product renders and the options picture follow in a later commit where not yet included.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
2026-10-29 Add Cycles product renders and the concept options picture
    Blender Cycles renders of the kit 1.9.1 model, rendered on Amish's Mac and captioned; media/options.png from the D3 option models (this also clears the failing docs check, which needs the picture); cards and PDFs rebuilt. The options picture labels option A as the current design unless project.yaml records Amish's choice.
2026-10-29 Add the concept options picture rendered from the D3 option models
    media/options.png from Blender Cycles panels of every option, rendered on Amish's Mac; the label reads CURRENT DESIGN unless project.yaml records Amish's choice. Clears the docs check, which needs th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

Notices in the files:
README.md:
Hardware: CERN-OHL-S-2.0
